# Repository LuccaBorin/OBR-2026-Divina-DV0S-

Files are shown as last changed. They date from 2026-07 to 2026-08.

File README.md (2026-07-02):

Esse é o local onde estou registrando todos os passos para a OBR Robocup Brasil 2026, onde coloco todos os scripts, svgs, stls do robô para comprovar que a jornada de aprendizagem da minha equipe.
Obs: Todos os arquivos feitos exclusivamente pelo aluno Lucca P. Borin.
Tarefas:
Testar com velocidade normal de 60 e para curva 65
Colocar tubinho lego no eixo da frente do motor e pendelo com enforca gato bem preso para entortar para dentro.
Diminuir  andar para frente do 90 já que coloquei para interseção

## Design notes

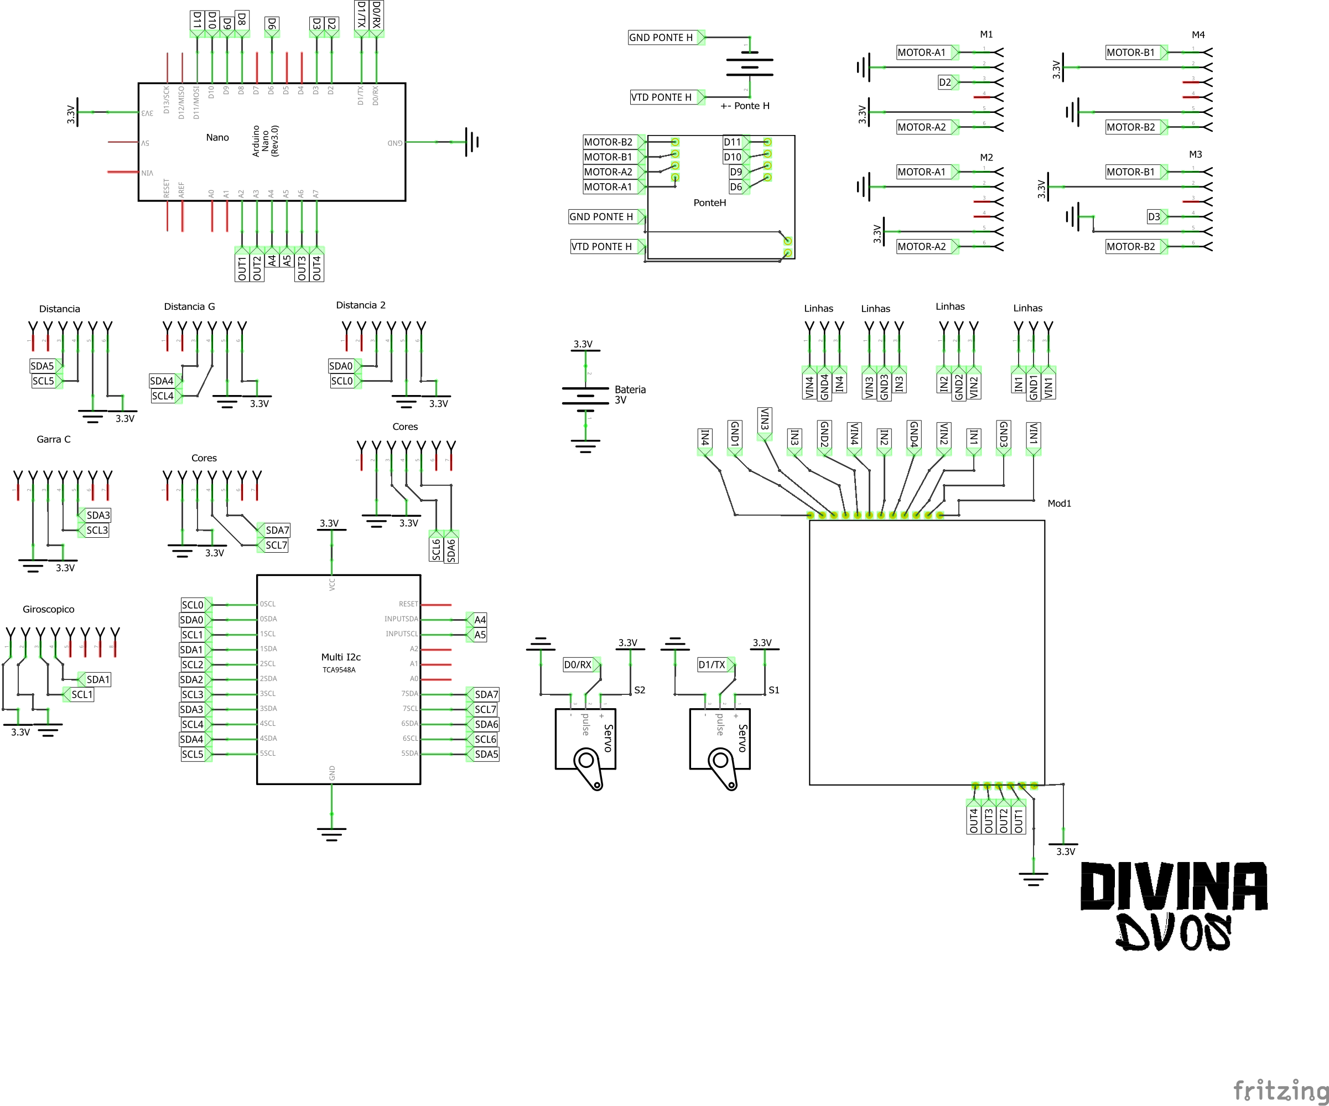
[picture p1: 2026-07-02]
PCB-projeto antigo/OBR2026upd_Esquemático.png

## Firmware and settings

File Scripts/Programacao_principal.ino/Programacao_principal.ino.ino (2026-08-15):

/*
 * ======================================================
 * Projeto  : Robô para a Olimpiada Brasileira de Robotica
 * Autor    : Lucca Pupo Borin
 * Data     : 02/07/2026
 * ======================================================
 * Hardware:
 *   Plataforma  : RoboCore Vespa (ESP32)
 *   Sensores    : MÓDULO  com 5 x TCRT5000, sendo o central à frente e os demais alinhados (infravermelho, leitura digital)
 *   Motor driver: DRV8837 (via biblioteca VespaMotors)
 *   Distância   : VL53L0X (sensor a laser), via multiplexador I2C (canal 0)
 *   Cor         : TCS34725 x2 (esquerda e direita), via multiplexador I2C (canais 3 e 4)
 *
 * Convenções de nomenclatura utilizadas:
 *   #define / pinos  → SNAKE_CASE_MAIUSCULO
 *   Tipos (enum)     → PascalCase
 *   Valores de enum  → SNAKE_MAIUSCULO  (sem prefixo de categoria)
 *   Funções          → camelCase  (padrão Arduino)
 *   Variáveis globais → camelCase
 *   Booleanos        → prefixo is/tem para leitura natural
 *   Variáveis locais → camelCase simples
 *
 * Lógica geral:
 *   Os sensores retornam HIGH quando detectam a linha (superfície
 *   escura) e LOW quando estão sobre o fundo claro. O robô ajusta
 *   sua direção com base em quais sensores estão ativos.
 *
 *   Sensores de ponta (PE / PD): indicam que o robô saiu muito
 *   da linha → executa curva de 90°.
 *   Sensores de centro (CE / CD): indicam desvio leve → correção
 *   suave de trajetória.
 *   Sensor central (CM): referência de alinhamento nas curvas de 90°.
 *
 *   O sensor de distância (VL53L0X) fornece a distância (em mm)
 *   até o obstáculo mais próximo à frente do robô. A troca de
 *   canal no multiplexador I2C (TCA9548A, endereço 0x70) é feita
 *   pela função selectChannel(), escrevendo direto no registrador
 *   de controle, sem biblioteca.
 * ======================================================
 */

// ======================================================
// BIBLIOTECAS
// ======================================================
#include <RoboCore_Vespa.h>
#include <Wire.h>
#include <Adafruit_VL53L0X.h>
#include <Adafruit_TCS34725.h>

// ======================================================
// OBJETOS
// ======================================================
VespaMotors motors;
Adafruit_VL53L0X distanciaC = Adafruit_VL53L0X();
Adafruit_VL53L0X distanciaL = Adafruit_VL53L0X();
// Tempo de integração mínimo (2.4ms) para não travar o loop de
// seguirLinha() — leitura de cor rápida, ao custo de menor precisão.
Adafruit_TCS34725 sensorCorEsquerda = Adafruit_TCS34725(TCS34725_INTEGRATIONTIME_2_4MS, TCS34725_GAIN_4X);
Adafruit_TCS34725 sensorCorDireita = Adafruit_TCS34725(TCS34725_INTEGRATIONTIME_2_4MS, TCS34725_GAIN_4X);

// ======================================================
// PINOS — SNAKE_CASE totalmente maiúsculo
//
// Mapa dos sensores (visão de cima do robô):
//
//   Esquerda ←————————————→ Direita
//   [PIN_SENSOR_PE] [PIN_SENSOR_CE] [PIN_SENSOR_CM] [PIN_SENSOR_CD] [PIN_SENSOR_PD]
//        L2               L1               M               R1              R2
//
// PE = Ponta Esquerda   CE = Centro Esquerda   CM = Centro Meio
// CD = Centro Direita   PD = Ponta Direita
// ======================================================
#define PIN_SENSOR_PE 17  // Ponta esquerda  (L2) -- TX2
#define PIN_SENSOR_CE 16  // Centro esquerda (L1) -- RX2
#define PIN_SENSOR_CM 18  // Centro meio     (M)  -- SCK
#define PIN_SENSOR_CD 5   // Centro direita  (R1) -- SS
#define PIN_SENSOR_PD 23  // Ponta direita   (R2) -- MOSI

// ======================================================
// I2C — Canal do multiplexador onde está o sensor de distância
// ======================================================
#define I2C_CANAL_DISTANCIA_C 0
#define I2C_CANAL_DISTANCIA_L 2   // Canal do MUX (TCA9548A, 0x70) onde o VL53L0X está ligado
#define I2C_CANAL_COR_ESQUERDA 3  // Canal do MUX (TCA9548A, 0x70) onde o TCS34725 esquerdo está ligado
#define I2C_CANAL_COR_DIREITA 4   // Canal do MUX (TCA9548A, 0x70) onde o TCS34725 direito está ligado

// ======================================================
// ENUM: Direcao
// ======================================================
enum Direcao {
  FRENTE,    // Ambos os motores para frente
  TRAS,      // Ambos os motores para trás
  DIREITA,   // Giro no próprio eixo para a direita
  ESQUERDA,  // Giro no próprio eixo para a esquerda
  PARAR      // Para os motores
};

// ======================================================
// ENUM: PerfilVelocidade
// Faixa válida: 0 a 100.
// Abaixo de ~30 o motor pode não vencer o atrito estático.
// ======================================================
enum PerfilVelocidade {
  VEL_DEFAULT = 83,
  VEL_BASE = 70,    // Velocidade padrão em linha reta
  VEL_CURVA = 75,   // Ajustada para manter a linha na curva
  VEL_SUBIDA = 75,  // Aumentada para vencer a gravidade
  VEL_DESCIDA = 55  // Reduzida para não perder o controle
};

// ======================================================
// ENUM: Desafio
// ======================================================
enum Desafio {
  FIM_DA_PISTA,
  VERDE_DIREITA,
  VERDE_ESQUERDA,
  OBSTACULO,                // Obstaculo
  INTERSECAO_SEM_MARCACAO,  // Interseções sem marcaçoes
  NOVENTA_GRAUS_ESQUERDA,   // Curva de 90 graus para esquerda
  NOVENTA_GRAUS_DIREITA,    // Curva de 90 graus para direita
  CURVA_LEVE_ESQUERDA,      // Curva leve/correção para esquerda
  CURVA_LEVE_DIREITA,       // Curva leve/correção para direita
  NENHUM                    // Andar para frente (não detectou nada)
};

// ======================================================
// ENUM: Direcao
// ======================================================
enum Cor {
  VERDE,
  VERMELHO,
  SEM_COR
};

// ======================================================
// VARIÁVEIS GLOBAIS — camelCase
// Booleanos com prefixo "is" para leitura natural nos ifs
// ======================================================
bool isSensorPE;  // Ponta esquerda  ativo = robô saiu muito à esq.
bool isSensorCE;  // Centro esquerda ativo = desvio leve à esq.
bool isSensorCM;  // Centro meio     ativo = robô centralizado
bool isSensorCD;  // Centro direita  ativo = desvio leve à dir.
bool isSensorPD;  // Ponta direita   ativo = robô saiu muito à dir.
int intDistanciaC;
int intDistanciaL;                                                // Última distância lida pelo VL53L0X (em cm)
uint16_t corEsquerdaR, corEsquerdaG, corEsquerdaB, corEsquerdaC;  // Última leitura RGB do TCS34725 esquerdo
uint16_t corDireitaR, corDireitaG, corDireitaB, corDireitaC;      // Última leitura RGB do TCS34725 direito
Desafio desafioAtual = NENHUM;                                    // Variavel que define o desafio que o robô esta enfrentando
Cor corDireita = SEM_COR;
Cor corEsquerda = SEM_COR;


// ======================================================
// PROTÓTIPOS DAS FUNÇÕES — camelCase, verbos no infinitivo
// ======================================================
void lerSensores();
void detectarDesafio();
void seguirLinha();
void mover(Direcao direcao, PerfilVelocidade velocidade, int tempo);
void selectChannel(uint8_t channel);

// ======================================================
// SETUP
// ======================================================
void setup() {
  // -------- DEBUG: liga o Monitor Serial -------
  Serial.begin(115200);
  Wire.begin();
  Wire.setClock(400000);  // I2C a 400kHz (Fast Mode) em vez de 100kHz -> troca de canal do MUX ~4x mais rápida

  // -------- Inicializa o sensor de distância no canal 0 do MUX --------
  selectChannel(I2C_CANAL_DISTANCIA_C);
  distanciaC.begin();
  distanciaC.startRangeContinuous();
  selectChannel(I2C_CANAL_DISTANCIA_L);
  distanciaL.begin();
  distanciaL.startRangeContinuous();

  // -------- Inicializa os sensores de cor (canais 3 e 4 do MUX) --------
  selectChannel(I2C_CANAL_COR_ESQUERDA);
  sensorCorEsquerda.begin();
  selectChannel(I2C_CANAL_COR_DIREITA);
  sensorCorDireita.begin();
}

// ======================================================
// LOOP
// ======================================================
void loop() {
  lerSensores();
  detectarDesafio();
  seguirLinha();
}

// ======================================================
// IMPLEMENTAÇÕES
// ======================================================

/*
 * selectChannel(channel)
 * -------------------------------------------------------
 * O QUE FAZ : Seleciona o canal ativo no multiplexador I2C
 *             (TCA9548A, endereço 0x70), escrevendo direto
 *             no seu registrador de controle.
 *
 * PARÂMETROS:
 *   channel → número do canal (0 a 7)
 * -------------------------------------------------------
 */
// Guarda o canal atualmente selecionado no MUX, para não escrever
// de novo no registrador quando o canal pedido já está ativo.
uint8_t canalAtualMUX = 0xFF;  // valor inválido inicial, força a 1ª troca

void selectChannel(uint8_t channel) {
  if (channel == canalAtualMUX) return;  // já está no canal certo, não faz nada
  Wire.beginTransmission(0x70);
  Wire.write(1 << channel);
  Wire.endTransmission();
  canalAtualMUX = channel;
}

/*
 * lerSensores()
 * -------------------------------------------------------
 * O QUE FAZ : Lê os 5 sensores infravermelhos e armazena
 *             o resultado nas variáveis globais isSensor_.
 *             Também troca para o canal do sensor de distância
 *             no multiplexador I2C (selectChannel) e lê o
 *             VL53L0X (modo contínuo, não-bloqueante) e, quando
 *             há uma medição nova pronta, atualiza distanciaCM
 *             (em cm). Se não houver medição nova, mantém o
 *             último valor lido.
 *             Também troca para os canais 3 e 4 do multiplexador
 *             I2C e lê os sensores de cor TCS34725 (esquerda e
 *             direita), armazenando os valores brutos de R, G, B
 *             e C (clear) nas variáveis globais correspondentes.
 *             Também imprime os valores no Monitor Serial
 *             para facilitar a depuração.
 *
 * QUANDO É CHAMADA:
 *   • No início e no fim de cada ciclo do loop()
 *   • Dentro de mover(), continuamente durante o
 *     movimento — garante que isSensorCM (e os demais)
 *     estejam sempre atualizados, mesmo enquanto o robô
 *     ainda está se movendo
 * -------------------------------------------------------
 */
void lerSensores() {
  isSensorPE = digitalRead(PIN_SENSOR_PE);
  isSensorCE = digitalRead(PIN_SENSOR_CE);
  isSensorCM = digitalRead(PIN_SENSOR_CM);
  isSensorCD = digitalRead(PIN_SENSOR_CD);
  isSensorPD = digitalRead(PIN_SENSOR_PD);

  // -------- SELECT CHANNEL: sensor de distância --------
  selectChannel(I2C_CANAL_DISTANCIA_C);
  intDistanciaC = distanciaC.readRange() / 10.0;
  selectChannel(I2C_CANAL_DISTANCIA_L);
  intDistanciaL = distanciaL.readRange() / 10.0;

  // -------- SELECT CHANNEL: sensores de cor (esquerda e direita) --------
  selectChannel(I2C_CANAL_COR_ESQUERDA);
  sensorCorEsquerda.getRawData(&corEsquerdaR, &corEsquerdaG, &corEsquerdaB, &corEsquerdaC);

  // -------- DETECÇÃO DE VERDE: SENSOR ESQUERDO --------
  // G precisa ser significativamente maior que R e B.
  // A comparação usa inteiros para evitar float e não adiciona delay.
  if (
    corEsquerdaC >= 20 && (uint32_t)corEsquerdaG * 100 > (uint32_t)corEsquerdaR * 112 && (uint32_t)corEsquerdaG * 100 > (uint32_t)corEsquerdaB * 112 && (uint32_t)corEsquerdaG * 100 >= ((uint32_t)corEsquerdaR + (uint32_t)corEsquerdaG + (uint32_t)corEsquerdaB) * 40) {
    corEsquerda = VERDE;
  } else {
    corEsquerda = SEM_COR;
  }

  selectChannel(I2C_CANAL_COR_DIREITA);
  sensorCorDireita.getRawData(&corDireitaR, &corDireitaG, &corDireitaB, &corDireitaC);

  // -------- DETECÇÃO DE VERDE: SENSOR DIREITO --------
  // G precisa ser significativamente maior que R e B.
  // A comparação usa inteiros para evitar float e não adiciona delay.
  if (
    corDireitaC >= 20 && (uint32_t)corDireitaG * 100 > (uint32_t)corDireitaR * 112 && (uint32_t)corDireitaG * 100 > (uint32_t)corDireitaB * 112 && (uint32_t)corDireitaG * 100 >= ((uint32_t)corDireitaR + (uint32_t)corDireitaG + (uint32_t)corDireitaB) * 40) {
    corDireita = VERDE;
  } else {
    corDireita = SEM_COR;
  }



  // -------- DEBUG: mostra no Monitor Serial qual desafio foi detectado --------
  /*
  Serial.print("PE: ");
  Serial.print(isSensorPE);
  Serial.print(" | CE: ");
  Serial.print(isSensorCE);
  Serial.print(" | CM: ");
  Serial.print(isSensorCM);
  Serial.print(" | CD: ");
  Serial.print(isSensorCD);
  Serial.print(" | PD: ");
  Serial.println(isSensorPD);
  Serial.print(" | Dist C: ");
  Serial.print(intDistanciaC);
  Serial.print(" cm | Dist L: ");
  Serial.print(intDistanciaL);
  Serial.println(" cm");
  Serial.print("Cor Esq -> R: ");
  Serial.print(corEsquerdaR);
  Serial.print(" G: ");
  Serial.print(corEsquerdaG);
  Serial.print(" B: ");
  Serial.print(corEsquerdaB);
  Serial.print(" C: ");
  Serial.print(corEsquerdaC);
  Serial.print(" | Cor Dir -> R: ");
  Serial.print(corDireitaR);
  Serial.print(" G: ");
  Serial.print(corDireitaG);
  Serial.print(" B: ");
  Serial.print(corDireitaB);
  Serial.print(" C: ");
  Serial.println(corDireitaC);
  */
}

/*
 * mover(direcao, velocidade, tempo)
 * -------------------------------------------------------
 * O QUE FAZ : Move o robô por um tempo determinado e para.
 *
 * PARÂMETROS:
 *   direcao   → para onde ir        (enum Direcao)
 *                 FRENTE   — avança em linha reta
 *                 TRAS     — recua em linha reta
 *                 DIREITA  — gira no próprio eixo à direita
 *                 ESQUERDA — gira no próprio eixo à esquerda
 *                 PARAR    — para imediatamente
 *
 *   velocidade → quão rápido ir     (enum PerfilVelocidade)
 *                 VEL_BASE    — velocidade normal
 *                 VEL_CURVA   — velocidade para curvas
 *                 VEL_SUBIDA  — velocidade para subidas
 *                 VEL_DESCIDA — velocidade para descidas
 *
 *   tempo     → quanto tempo durar  (milissegundos)
 *                 Ex: 500 = meio segundo
 *
 * NÃO-BLOQUEANTE: em vez de delay(), usa millis() para
 * cronometrar o movimento. Isso permite que lerSensores()
 * continue sendo chamada durante o próprio movimento,
 * mantendo as leituras sempre atualizadas — importante
 * para os laços while() das curvas de 90° em seguirLinha().
 * -------------------------------------------------------
 */
void mover(Direcao direcao, PerfilVelocidade velocidade, int tempo) {
  lerSensores();
  int spd = (int)velocidade;  // converte o enum para int
  if (spd < 0) spd = 0;       // limite inferior: mínimo 0
  if (spd > 100) spd = 100;   // limite superior: máximo 100

  switch (direcao) {
    case FRENTE:
      motors.forward(spd);
      break;

    case TRAS:
      motors.backward(spd);
      break;

    case DIREITA:
      // Motor esquerdo avança + direito recua = giro à direita
      motors.setSpeedLeft(spd);
      motors.setSpeedRight(-spd);
      break;

    case ESQUERDA:
      // Motor direito avança + esquerdo recua = giro à esquerda
      motors.setSpeedLeft(-spd);
      motors.setSpeedRight(spd);
      break;

    case PARAR:
    default:
      motors.stop();
      break;
  }

  // -------- ESPERA NÃO-BLOQUEANTE (substitui delay(tempo)) --------
  // Em vez de travar a CPU, fica em loop lendo os sensores
  // continuamente até o tempo definido se esgotar.
  unsigned long tempoInicio = millis();
  while ((unsigned long)(millis() - tempoInicio) < (unsigned long)tempo) {
    lerSensores();
  }

  motors.stop();

  // Atualiza os sensores após o movimento para que o próximo
  // passo de seguirLinha() — ou o while() das curvas —
  // tome decisões com dados frescos
  lerSensores();
}

/*
 * detectarDesafio()
 * -------------------------------------------------------
 * O QUE FAZ : Analisa os sensores e determina qual
 *             situação o robô está enfrentando,
 *             armazenando o resultado em desafioAtual.
 *
 * PRIORIDADE DAS DECISÕES:
 *   1. isSensorPE ativo → curva de 90° à esquerda
 *
 *   2. isSensorPD ativo → curva de 90° à direita
 *
 *   3. isSensorCE ativo → correção suave à esquerda
 *
 *   4. isSensorCD ativo → correção suave à direita
 *
 *   5. Nenhum dos casos acima
 *      → segue em frente (NENHUM)
 *
 * POR QUE ESTA FUNÇÃO EXISTE:
 *   A decisão sobre qual movimento executar fica
 *   separada da execução do movimento em si.
 *   Assim, seguirLinha() apenas executa a ação
 *   correspondente usando um switch, deixando o
 *   código mais organizado e facilitando a inclusão
 *   de novos desafios no futuro.
 * -------------------------------------------------------
 */
void detectarDesafio() {
  if (corEsquerda == VERDE || corDireita == VERDE) {
    if (corEsquerda == VERDE) {
      // -------- VERDE NA DIREITA --------
      desafioAtual = VERDE_ESQUERDA;
    } else if (corDireita == VERDE) {
      // -------- VERDE NA DIREITA --------
      desafioAtual = VERDE_DIREITA;
    }
  } else if (intDistanciaC <= 10) {
    if (intDistanciaC <= 10) {
      // -------- OBSTACULO --------
      desafioAtual = OBSTACULO;
    }
  } else if (isSensorPE || isSensorCE || isSensorCM || isSensorCD || isSensorPD) {  // -------- SENSORES VENDO PRETO EM QUALQUER LUGAR --------
    if (isSensorPE && isSensorPD && isSensorCM) {
      // -------- INTERSEÇÃO DUAS LINHAS SEM COR --------
      desafioAtual = INTERSECAO_SEM_MARCACAO;
    } else if (isSensorPE && !isSensorPD && isSensorCE) {
      // -------- CURVA DE 90° PARA A ESQUERDA --------
      desafioAtual = NOVENTA_GRAUS_ESQUERDA;

    } else if (isSensorPD && !isSensorPE && isSensorCD) {
      // -------- CURVA DE 90° PARA A DIREITA --------
      desafioAtual = NOVENTA_GRAUS_DIREITA;

    } else if (isSensorCE) {
      // -------- CORREÇÃO SUAVE PARA A ESQUERDA --------
      desafioAtual = CURVA_LEVE_ESQUERDA;

    } else if (isSensorCD) {
      // -------- CORREÇÃO SUAVE PARA A DIREITA --------
      desafioAtual = CURVA_LEVE_DIREITA;

    } else {
      // -------- LINHA RETA / NENHUM SENSOR ATIVO --------
      desafioAtual = NENHUM;
    }
  }

  // -------- DEBUG: mostra no Monitor Serial qual desafio foi detectado --------
  /*
  Serial.print("Desafio detectado: ");
  switch (desafioAtual) {
    case VERDE_DIREITA:
      Serial.println("VERDE_DIREITA");
      break;
    case OBSTACULO:
      Serial.println("OBSTACULO");
      break;
    case INTERSECAO_SEM_MARCACAO:
      Serial.println("INTERSECAO_SEM_MARCACAO");
      break;
    case NOVENTA_GRAUS_ESQUERDA:
      Serial.println("NOVENTA_GRAUS_ESQUERDA");
      break;
    case NOVENTA_GRAUS_DIREITA:
      Serial.println("NOVENTA_GRAUS_DIREITA");
      break;
    case CURVA_LEVE_ESQUERDA:
      Serial.println("CURVA_LEVE_ESQUERDA");
      break;
    case CURVA_LEVE_DIREITA:
      Serial.println("CURVA_LEVE_DIREITA");
      break;
    case NENHUM:
    default:
      Serial.println("NENHUM (linha reta)");
      break;
  }*/
}
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

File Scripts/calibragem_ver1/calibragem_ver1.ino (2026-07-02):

#define out1 36
#define out2 39
#define led 15

int medB, maxB, minB, valB1, valB2, valB3;
int medP, maxP, minP, valP1, valP2, valP3;
int leitura1, leitura2;

void setup() {
  pinMode(out1, INPUT);
  pinMode(out2, INPUT);
  pinMode(15, OUTPUT);
  Serial.begin(9600);
}

void loop() {
  //--- PRETO 1 ---
  digitalWrite(led,LOW);
  delay(4000);
  leitura1 = analogRead(out1);
  leitura2 = analogRead(out2);
  delay(1000);
  digitalWrite(led,HIGH);
  valP1 = (leitura1 + leitura2) / 2;
  delay(1000);

  //--- BRANCO 1 ---
  digitalWrite(led,LOW);
  delay(4000);
  leitura1 = analogRead(out1);
  leitura2 = analogRead(out2);
  delay(1000);
  digitalWrite(led,HIGH);
  valB1 = (leitura1 + leitura2) / 2;
  delay(1000);

  //--- PRETO 2 ---
  digitalWrite(led,LOW);
  delay(4000);
  leitura1 = analogRead(out1);
  leitura2 = analogRead(out2);
  delay(1000);
  digitalWrite(led,HIGH);
  valP2 = (leitura1 + leitura2) / 2;
  delay(1000);

  //--- BRANCO 2 ---
  digitalWrite(led,LOW);
  delay(4000);
  leitura1 = analogRead(out1);
  leitura2 = analogRead(out2);
  delay(1000);
  digitalWrite(led,HIGH);
  valB2 = (leitura1 + leitura2) / 2;
  delay(1000);

  //--- PRETO 3 ---
  digitalWrite(led,LOW);
  delay(4000);
  leitura1 = analogRead(out1);
  leitura2 = analogRead(out2);
  delay(1000);
  digitalWrite(led,HIGH);
  valP3 = (leitura1 + leitura2) / 2;
  delay(1000);

  //--- BRANCO 3 ---
  digitalWrite(led,LOW);
  delay(4000);
  leitura1 = analogRead(out1);
  leitura2 = analogRead(out2);
  delay(1000);
  digitalWrite(led,HIGH);
  valB3 = (leitura1 + leitura2) / 2;
  delay(1000);

  //--- CALCULA MÉDIAS ---
  medP = (valP1 + valP2 + valP3) / 3;
  maxP = medP + 20;
  minP = medP - 20;

  medB = (valB1 + valB2 + valB3) / 3;
  maxB = medB + 20;
  minB = medB - 20;

  //--- MOSTRA RESULTADOS ---
  Serial.println("==== Calibragem ====");
  
  Serial.print("Branco -> Media: ");
  Serial.print(medB);
  Serial.print(" | Max: ");
  Serial.print(maxB);
  Serial.print(" | Min: ");
  Serial.println(minB);

  Serial.print("Preto -> Media: ");
  Serial.print(medP);
  Serial.print(" | Max: ");
  Serial.print(maxP);
  Serial.print(" | Min: ");
  Serial.println(minP);

  while (true);
}

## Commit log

2026-06-22 Controle de TCS3472 com Multiplexador I2c e Led RGB
2026-06-22 Create Controle de TCS3472 com Multiplexador I2c e Led RGB
2026-06-22 Update Controle de TCS3472 com Multiplexador I2c e Led RGB
2026-06-26 Create Teste dos Motores
2026-07-02 Colocando arquivos antigos
    [OBR2026back.fzz, OBR2026upd.fzz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]
